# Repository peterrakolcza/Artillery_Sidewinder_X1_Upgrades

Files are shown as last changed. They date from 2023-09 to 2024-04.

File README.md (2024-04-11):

# Artillery Sidewinder X1 🖨️





The present repository is dedicated to optimizing the Artillery Sidewinder X1 3D printer. If you're in search of enhancements to apply to your Sidewinder X1, you've landed on the right page. Within this repository, I'll be sharing my recommended upgrades for the Sidewinder X1. This information should streamline your decision-making process when considering modifications for your Sidewinder X1.

While many acknowledge the Sidewinder X1 as a proficient machine in its original setup, there will always be enthusiasts seeking to maximize their printer's performance.

I partially concur that the X1 operates effectively in its standard configuration. My Artillery Genius (the X1’s counterpart) currently operates with its default settings and produces impressive prints. However, I opted to enhance the X1 to address minor issues I encountered and to compile guides and tutorials.

<br>
   
## 🚀 Upgrades

- [Small upgrades](#-small-upgrades)
    - [Aluminum Extruder Idler Lever](#aluminum-extruder-idler-lever)
    - [Gantry Support](#gantry-support)
    - [Squaring the Gantry](#squaring-the-gantry)
    - [Better Quality Nozzles](#better-quality-nozzles)
    - [Jaw Couplers with Rubber Interface](#jaw-couplers-with-rubber-interface)
    - [POM Anti-Backlash Nuts](#pom-anti-backlash-nuts)
    - [Bi-Metal Heatbreak](#bi-metal-heatbreak)
- [LED Light](#-led-light)
- [BLTouch for Auto Bed Leveling](#-bltouch-for-auto-bed-leveling)
    - [UBL (Unified Bed Leveling)](#-ubl-(unified-bed-leveling)) 
- [Marlin + TFT Firmware](#-marlin--tft-firmware)
- [OctoPi](#-octopi)
- [Obico for OctoPrint](#-obico-for-octoprint)

## 🤏 Small upgrades

You can find detailed explanations and recommended parts about each upgrade on this website ([Artillery Sidewinder X1 Upgrades – Paid and Free](https://3dprintbeginner.com/sidewinder-x1-upgrades/)).

### Aluminum Extruder Idler Lever

Replace the stock plastic extruder idler lever with a more durable and efficient aluminum lever for better extrusion performance.

### Gantry Support

Strengthen the printer's gantry system to improve stability and precision during printing. STL files are included in the repository.
[Video Tutorial](https://www.youtube.com/watch?v=9TPCdesemes) 

### Squaring the Gantry

Instructions on how to properly square the gantry for optimal printer performance and print accuracy. STL files are included in the repository.
[Video Tutorial](https://www.youtube.com/watch?v=KmeYlX6eXGE)

### Better Quality Nozzles

Upgrade to higher-quality nozzles to enhance printing precision and reduce clogs.

### Jaw Couplers with Rubber Interface

Upgrade the jaw couplers to those with a rubber interface to minimize vibrations and improve print quality.

### POM Anti-Backlash Nuts

Replace standard nuts with POM anti-backlash nuts for smoother and more precise movements.

### Bi-Metal Heatbreak

Replace the heatbreak with a bi-metal version for improved heat dissipation and reduced heat creep.

## 💡 LED Light

Install LED lighting to illuminate the print bed and enhance visibility during printing. I just added a 24V led strip to the power supply and routed the cable through the gantry.

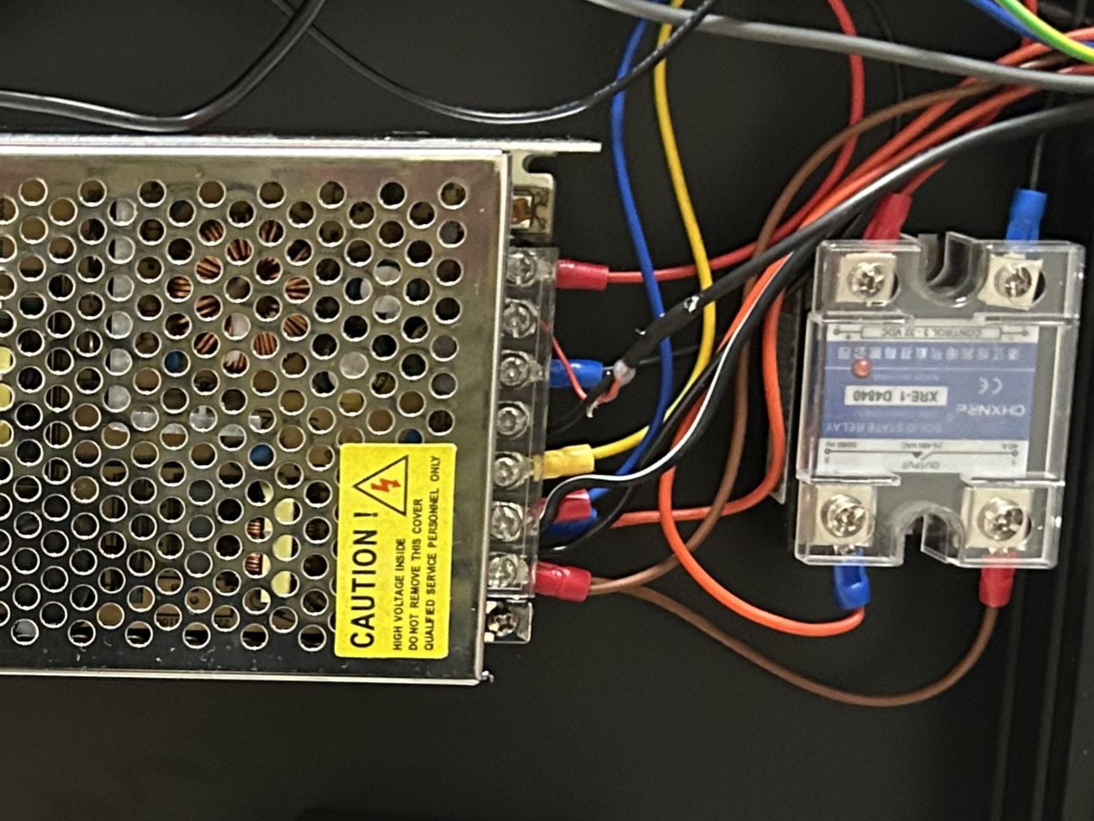
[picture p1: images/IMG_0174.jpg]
24V LED


## 💉 BLTouch for Auto Bed Leveling

The Sidewinder X1 is a 3D printer known for its large print volume and reliability. The BLTouch is an auto-bed leveling sensor commonly used in 3D printers to help achieve a level print bed, which is crucial for successful 3D prints. Installing a BLTouch on the Sidewinder X1 can greatly improve the quality of your prints by ensuring the first layer adheres well to the bed and is consistent across the entire print surface.

There is a great video tutorial ([Youtube Tutorial](https://www.youtube.com/watch?v=n8kRF9XfeNo)) showing the whole process, but here are the general steps to install a BLTouch on a Sidewinder X1:

1. Gather the Required Components:
    - BLTouch auto-bed leveling sensor
    - Mounting bracket for the BLTouch (you may need to 3D print)
    - Wires and connectors for connecting the BLTouch to the printer's electronics (usually comes with the BLTouch)

2. Print or Acquire a Mounting Bracket:
    - Print or acquire a suitable mounting bracket for the BLTouch that is compatible with the Sidewinder X1's frame and hotend assembly.

3. Install the Mounting Bracket:
    - Attach the mounting bracket to the hotend assembly of the Sidewinder X1. Ensure that the BLTouch sensor will be positioned accurately and at an appropriate height above the print bed.

4. Wire Connection:
    - Connect the BLTouch to the appropriate pins on the control board of the Sidewinder X1. You'll need to connect the necessary wires for power, ground, and signal.
    - It is recommended to use the built-in LED on the extruder for easy installation.

5. Firmware Configuration:
    - Modify the firmware of the 3D printer to accommodate the BLTouch sensor. You will need to enable the BLTouch feature in the firmware and configure the sensor's settings, such as offsets and probe points.
    - Refer to [Marlin + TFT Firmware](#marlin--tft-firmware).

6. Calibration:
    - Use the printer's firmware interface to calibrate the BLTouch. This involves adjusting the probe offsets, homing the printer, and fine-tuning the Z-offset to ensure the nozzle is at the correct height above the bed.

After finishing everything the connection to the main board should look like this:

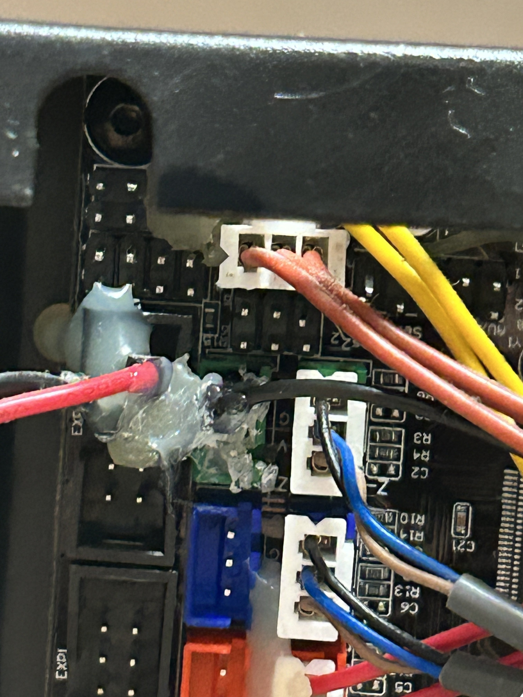
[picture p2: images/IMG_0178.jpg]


### 📐 UBL (Unified Bed Leveling)

The Unified Bed Leveling System (UBL) provides a comprehensive set of resources to produce the best bed leveling results possible. See the full Unified Bed Leveling documentation for more details.

Unified Bed Leveling System (UBL) offers two options for bed leveling: 
1) leveling before every print
2) loading an existing mesh from EEPROM which was created earlier

In our scenario, the second option is ideal as the glass surface does not undergo frequent changes. This means that once the mesh is established and saved, it can be reliably applied to subsequent prints without the need for repeated leveling procedures. This ensures consistent print quality and saves time by avoiding repetitive calibration steps.

To manually create a mesh and save it to the EEPROM (Slot 0):
```
G28       ; home all axes
M420 S0   ; Turning off bed leveling while probing, if firmware is set to restore after G28
M190 S65  ; (optional) wait for the bed to get up to temperature
G29 P1    ; automatically populate mesh with all reachable points
G29 P3    ; infer the rest of the mesh values
G29 P3    ; infer the rest of the mesh values again
M420 S1 V ; enabled leveling and report the new mesh
G29 S0    ; Save UBL mesh points to slot 0 (EEPROM).
G29 F 10.0 ; Set Fade Height for correction at 10.0 mm. Just to make sure...
G29 A     ; Activate the UBL System.
M500      ; save the current setup to EEPROM
M140 S0   ; cooling down the bed
```

Start GCODE for loading an existing mesh from EEPROM (Slot 0) which was created earlier:
```
M190 S65  ; preheat bed for mesh adjustments
G28       ; home all axes
G29 L0    ; load the mesh from Slot 0
G29 J2    ; measure bed tilt and apply to the existing mesh
G29 A     ; make sure UBL is active
```

Things worth knowing:
- `G29 L<index>`: will restore the active state (active/inactive) to what it was when the mesh was saved. That means sending `G29 A` first is useless.
- `M420`: Get and/or set bed leveling state.
- `G29 F 10.0`: Fade height (UBL only! For others use `M420 Z<fade>`). If no number is specified for the command, 10mm is assumed to be reasonable. Also, `G29 F<fade>` doesn't need to be sent unless you want to change the fade height from what was set in the firmware.

## 🖥️ Marlin + TFT Firmware

Upgrade the printer's firmware to Marlin and integrate a TFT touchscreen for an improved user interface and enhanced control. Use the included firmware in the repository for the main board (aswx1_marlin_fw_2.1.2_bltouch_waggster_mod_z_max_used.rar) and TFT panel (artillery_tft_fw_1.27.x_patch_9.5.rar).

## 🐙 OctoPi

OctoPi (OctoPrint on Raspberry Pi) is a popular open-source software that allows you to remotely monitor and control your 3D printer through a web interface. Setting up OctoPi with the Sidewinder X1 allows you to have a more convenient and remote way to manage your 3D prints. Here are the steps to set up OctoPi with the Sidewinder X1:

1. Obtain a Raspberry Pi:
Obtain a Raspberry Pi (e.g., Raspberry Pi 4) and a suitable microSD card (16GB or larger). Install the latest version of OctoPi on the microSD card.

2. Connect the Raspberry Pi:
Insert the microSD card into the Raspberry Pi, connect the Raspberry Pi to your local network using an Ethernet cable or Wi-Fi, and power it up.

3. Access OctoPrint Interface:
On a computer connected to the same network, open a web browser and enter the IP address of your Raspberry Pi or "http://octopi.local" (if Bonjour is supported on your network). The OctoPrint interface should load.

4. Initial Setup:
Follow the on-screen instructions to complete the initial setup, including creating a username and password.

5. Connect Sidewinder X1 to OctoPrint:
Connect the Sidewinder X1 to the Raspberry Pi using a USB cable. The USB cable should be plugged into the Raspberry Pi's USB port.

6. Configure OctoPrint:
In OctoPrint's settings, configure the printer profile for the Sidewinder X1, including the bed size, print volume, and other relevant settings.

7. Test Connection:
Verify that OctoPrint is communicating with the Sidewinder X1 by homing the printer and sending manual movement commands.

8. Install Plugins (Optional):
Customize OctoPrint by installing plugins that enhance its functionality, such as plugins for temperature monitoring, timelapse recording, and more.

9. Remote Monitoring and Control:
Use OctoPrint's web interface to remotely monitor and control your Sidewinder X1. You can start, pause, and stop prints, monitor print progress, and even receive notifications.

10. Secure Access (Optional):
Consider securing your OctoPrint instance by enabling access control, using HTTPS, and configuring firewall rules to restrict access to trusted IP addresses. Refer to [Obico for OctoPrint](#-obico-for-octoprint).

Sample wiring inside of the Sidewinder X1 for a cleaner look:

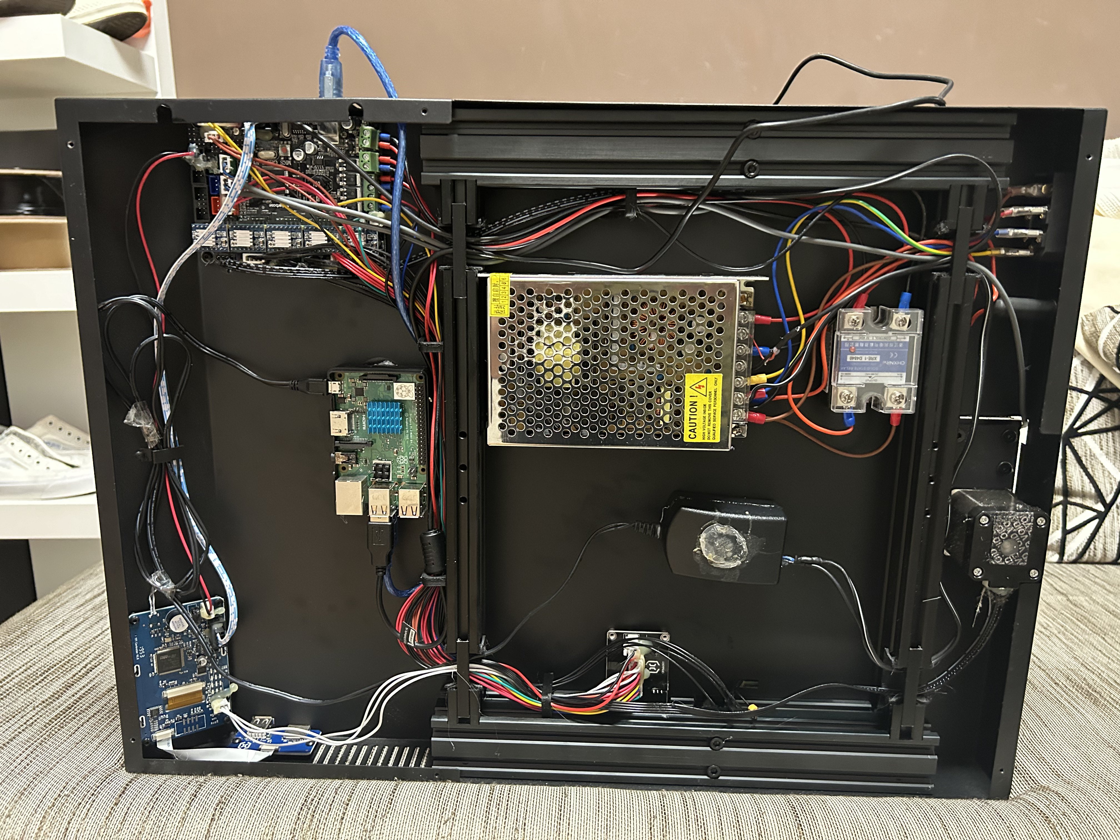
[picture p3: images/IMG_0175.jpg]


### 🛠️ Compatibility and Usage with OctoPrint

The serial bus with the main board (MKS GEN L v1.0) is shared between TFT and Octoprint / Pronterface etc… This means that printing from Octoprint / Pronterface etc… causes Marlin to receive gcodes from Octoprint and TFT at the same time (there are collisions). This will let Marlin reply with error messages, that will be displayed on both Octoprint and TFT display, such as:

```
Line Number is Not Last Line Number +1 Last Line 1686.
```

In order to avoid the problem, when printing with Octoprint/Pronterface etc… put the TFT in “Listening Mode” pressing on the button:
``` 
Menu => Settings => Connection => ON
```

#### 📌 Note:

- This limitation is not due to bugs on the TFT firmware but it is an hardware limitation on MKS GEN L v1.0 main board
- The mode state is stored on FLASH allowing to restore the mode at startup. This allows to power on/off the printer remotely and to control the printer via USB without the need of any touch (from the user) on the display to engage the mode

### 🛠️ Printing from Remote Host

After the TFT is set to Listening Mode (see section Integration with OctoPrint),

OctoPrint, ESP3D, Pronterface etc, connected to a TFT's or mainboard's serial port, can host a print (print handled by the host) and optionally can trigger some actions to the TFT sending specific G-codes. Refer to the documentation.

### 🛠️ Filament Sensor with OctoPi

Adding the filament sensor to your OctoPi for remote monitoring and control, is a great way to enhance your 3D printing experience. A filament sensor can help you avoid failed prints due to filament runouts. As it is connected to the TFT panel, it cannot be used directly when printing from remote host (OctoPi).

However, you can wire it to the GPIO pins on the OctoPi and use the *Filament Sensor Simplified* plugin. **Note: you will not able to use the filament sensor when printing from USB or SD card!**

I used toothpicks to get out the crimpled wires from the connectors and use new connectors. If you are using the same power supply for the OctoPi as for your main board, then you can leave the 3.3V and GND wires in-place and connect the sensor wire to GPIO24 (as they share the common ground). Otherwise, you have to wire everything into the OctoPi (as I did). Refer to the pictures for wiring, I have used 3.3V, GND and GPIO24 pins on the OctoPi.

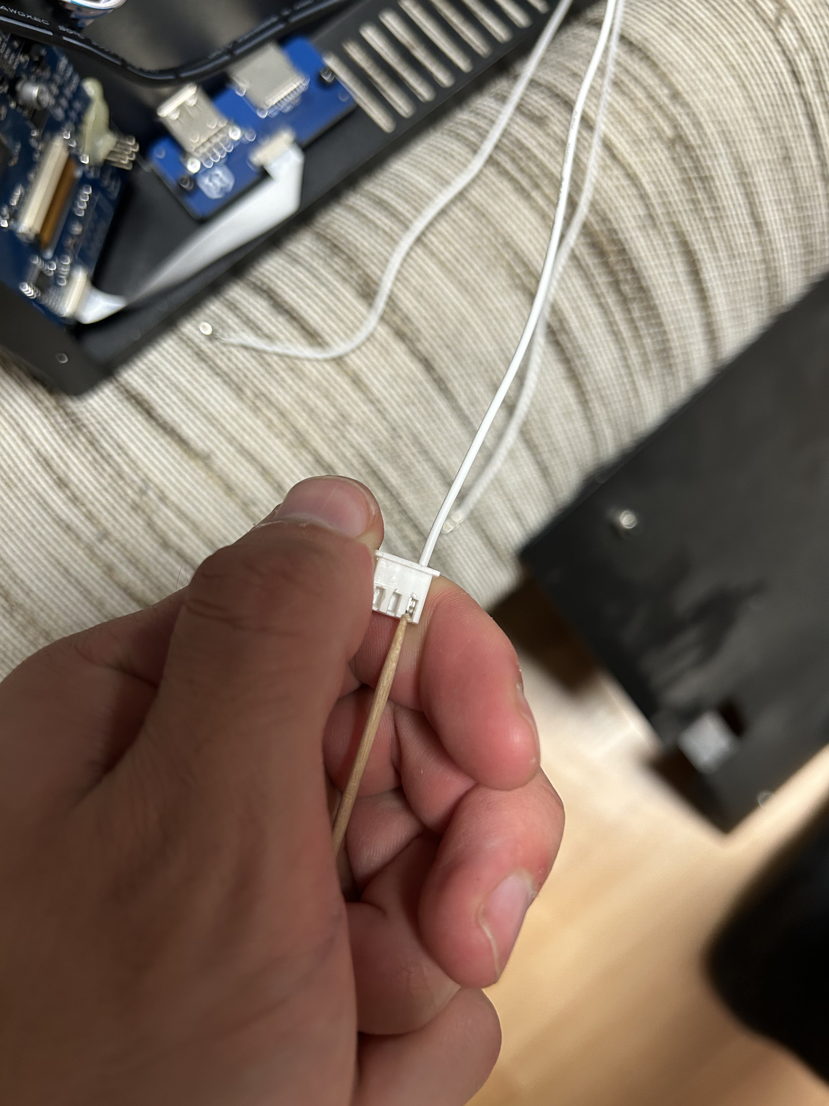
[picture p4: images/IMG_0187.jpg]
Wiring 1

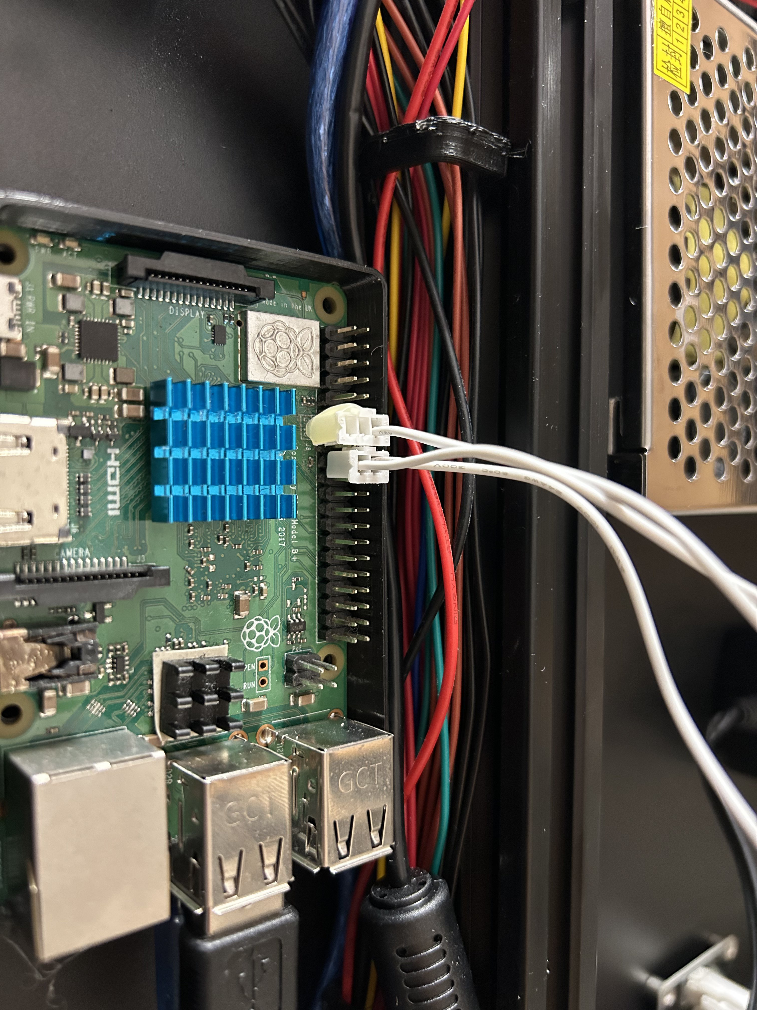
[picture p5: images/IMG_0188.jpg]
Wiring 2


## 📷 Obico for OctoPrint

Obico is an OctoPrint plugin designed to enhance 3D printing workflows. It provides improved visualizations, analytics, and additional features to optimize your printing experience, making it a valuable tool for managing your 3D printer and prints within the OctoPrint ecosystem.

I am recommending to use a self-hosted server as it makes the whole setup free. Refer to [Self-hosted Obico Server Guides](https://www.obico.io/docs/server-guides/) for a more detailed guide.

## 📚 References
- [Artillery Sidewinder X1 Upgrades – Paid and Free](https://3dprintbeginner.com/sidewinder-x1-upgrades/)
- [Artillery Sidewinder X1 / X2 / Genius TFT FW + Marlin FW (for X1) + M600 support + Marlin mode …](https://3dfablab.wordpress.com/2021/12/07/artillery-sidewinder-x1-x2-genius-tft-fw-marlin-fw-for-x1-m600-support-marlin-mode/)
- [Self-hosted Obico Server Guides](https://www.obico.io/docs/server-guides/)
- [BLTouch for Auto Bed Leveling](https://www.youtube.com/watch?v=1uuxTWJZowo) 
- [Sidewinder X1 Gantry Support](https://www.youtube.com/watch?v=9TPCdesemes) 
- [Squaring the gantry on the Sidewinder X1 3D printer, the EASY way.](https://www.youtube.com/watch?v=KmeYlX6eXGE)

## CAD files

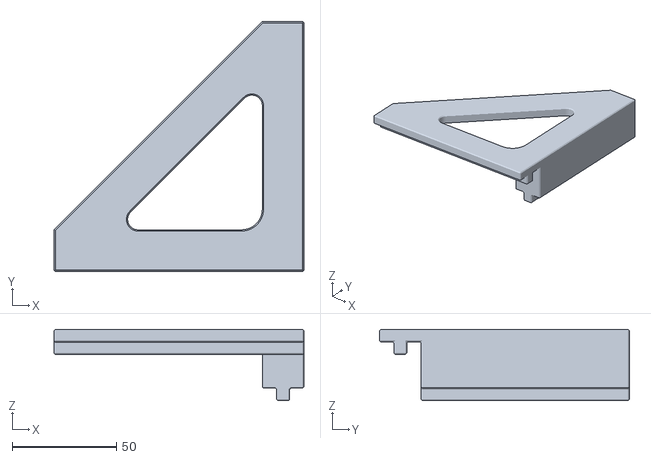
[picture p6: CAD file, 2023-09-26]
Gantry Square.STL
120.0 x 120.0 x 34.2
